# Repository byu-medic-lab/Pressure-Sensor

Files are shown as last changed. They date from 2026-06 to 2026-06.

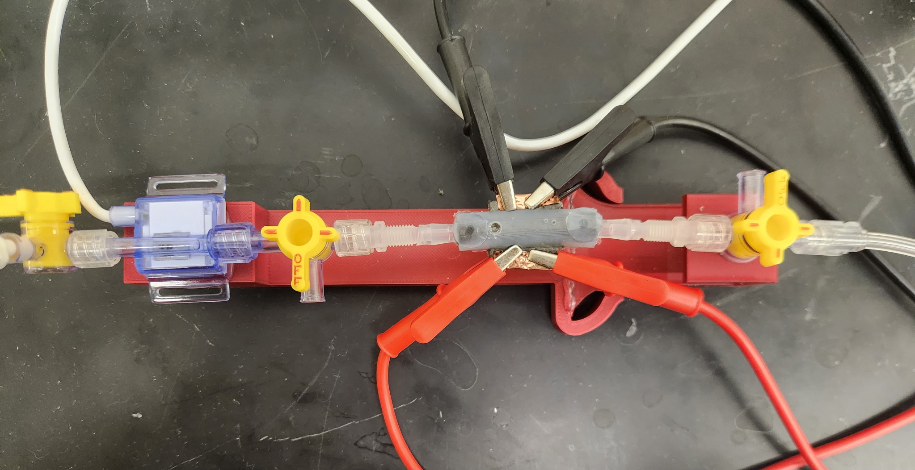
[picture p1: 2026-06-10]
images/Sensor_Setup.jpg

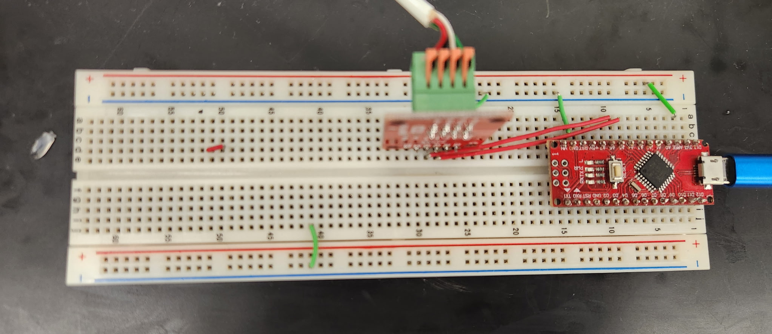
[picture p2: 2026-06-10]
images/Pressure_Sensor.jpg

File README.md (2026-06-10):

# Pressure Sensor Characterization System

This repository contains the software, setup notes, images, and 3D-print files for a lab pressure/resistance characterization system. The system is used to measure how the electrical resistance of a conductive polymer composite sensor changes under controlled pressure.

The main software is a Python desktop GUI built with PyQt6. It controls and records data from:

- A serial pressure sensor that outputs raw integer pressure readings
- A Fluke 8808A digital multimeter measuring resistance
- A New Era NE-500/NE-501 syringe pump over RS-232

The GUI supports pressure calibration, syringe pump movement calibration, automated pressure cycling, CSV logging, and SVG graph generation.

---

## Repository Layout

```text
Pressure-Sensor/
  README.md
  src/
    main.py
    pyproject.toml
    app/
    devices/
    gui/
    protocols/
    tests/
    hysteresis_tool/
    fluke_resistance_logger.py
    fluke_resistance_decay_graph.py
    pump_push_water_10s.py
    add_average_trendline_equations.py
  Instructions/
    Pressure_Resistance_Characterization_Setup.md
    Sensor_Fabrication_Protocol.md
    Sensor_Behavior.md
    Introduction.md
  images/
    Final_Sensor.png
    Fluke_Multimeter.jpg
    Manometer.jpg
    Pressure_Sensor.jpg
    Sensor_Setup.jpg
    Syringe_Pump.jpg
  STL/
    NCCF_Bottom.STL
    NCCF_Top.STL
    Silicone_Bottom.STL
    Silicone_Top.STL
```

The runnable Python project is inside the `src/` folder.

---

## Hardware Used

The software is designed for this lab setup:

- Pressure sensor connected through a serial interface
- Fluke 8808A digital multimeter
- NE-500/NE-501 syringe pump
- USB-to-serial adapters
- Water manometer
- Conductive polymer composite sensor fixture
- 3D printed sensor/test fixture components

The app can also run in simulation mode without hardware, but real data collection requires the devices above and the correct serial ports.

---

## Software Requirements

Install these before running the project:

- Python 3.11 or newer
- Git
- Windows is recommended because the GUI and serial-port workflow were developed and tested on Windows

Python packages are installed from `src/pyproject.toml`:

- PyQt6
- pyserial
- pytest, for running tests

---

## Download The Code From GitHub

Open PowerShell and run:

```powershell
cd "C:\Users\YOUR_USERNAME\Documents"
git clone https://github.com/byu-medic-lab/Pressure-Sensor.git
cd Pressure-Sensor
```

Replace `YOUR_USERNAME` with your Windows username if needed.

---

## Create The Python Environment

From the repository folder:

```powershell
cd src
python -m venv .venv
.venv\Scripts\activate
python -m pip install --upgrade pip
python -m pip install -e ".[test]"
```

This creates a local virtual environment and installs all required packages.

---

## Run The Tests

From the `src/` folder with the virtual environment activated:

```powershell
python -m pytest
```

All tests should pass before using the GUI for data collection.

---

## Run The Main GUI

From the `src/` folder with the virtual environment activated:

```powershell
python main.py
```

The GUI will open as a desktop application.

---

## Basic GUI Workflow

### 1. Prepare The System

Before starting:

- Select the correct serial port for each device
- Connect and test device communication
- Make sure the pressure system is vented to ambient
- Make sure the pressure sensor reading is stable
- Make sure the Fluke reading is stable
- Remove the water column unless doing manometer calibration
- Place the syringe pump at the known starting position
- Confirm the tubing and fluid path are ready before calibration or automated testing

### 2. Connect Devices

In the **Device connections** section:

- Select the pressure sensor serial port
- Select the Fluke serial port
- Select the syringe pump serial port
- Click **Connect** for each device
- Use **Test** to verify communication

Serial ports are not hardcoded. They must be selected from the dropdowns.

### 3. Calibrate Pressure With The Manometer

In the **Calibration** tab:

1. Enter the manometer pressure point in `cm H2O`
2. Set the recording time
3. Click **Start recording window**
4. The app records pressure samples for the selected time
5. The app averages the window and stores the point
6. The manometer point automatically increases by 10 cm H2O
7. Repeat for all calibration points
8. Click **Fit/save coefficients**

The pressure conversion used by the app is:

```text
mmHg = cmH2O * 0.735559
```

The fitted pressure model is:

```text
pressure_mmhg = slope * raw_pressure_integer + intercept
```

### 4. Calibrate Syringe Pump Movement

In the same **Calibration** tab:

1. Click **Start auto syringe calibration**
2. The app records pressure before movement
3. The pump moves using the fixed calibration sequence
4. The app records pressure after movement
5. The process repeats automatically
6. Click **Fit syringe calibration** when complete

The current fixed syringe calibration sequence uses:

```text
Pump motion time: 5 s
Movement rate: 60 mL/min
Direction: INF first
Average time: 5 s
Cycles: 5 up and 5 back
```

The app fits separate increasing and decreasing pump-response behavior.

### 5. Run Automated Test

In **Run automated test**:

1. Enter an experiment ID
2. Add operator notes
3. Choose an output folder
4. Enter start pressure, stop pressure, pressure interval, and optional cycle count
5. Leave time interval blank to use the automatic 3-tau settling behavior
6. Click **Start automated test**

The app moves to the start pressure before logging begins. During the test it records pressure and resistance at stopped pressure intervals.

---

## Output Files

Each automated run creates a timestamped output folder. The final folder normally contains:

```text
metadata.csv
resistance_vs_pressure_mmhg.svg
resistance_vs_pressure_fits.svg
plotted_pressure_resistance_points.csv
pressure_cm_vs_mmhg_points.csv
```

`metadata.csv` contains run information such as experiment ID, operator notes, serial settings, and calibration coefficients.

`plotted_pressure_resistance_points.csv` contains only:

```text
average_pressure_mmhg
average_resistance_ohms
```

The SVG graphs include equation text for average increasing and decreasing pressure sweeps.

---

## Standalone Scripts

The `src/` folder includes several standalone helper scripts.

### Fluke Resistance Logger

Records Fluke resistance vs time without opening the main GUI:

```powershell
python fluke_resistance_logger.py
```

This creates CSV and SVG files in:

```text
src/fluke_logs/
```

Only one program can use the Fluke COM port at a time. Close or disconnect the main GUI before running this logger.

### Fluke Exponential Decay Graph

Creates a resistance-vs-time graph with an exponential fit and 3-tau marker:

```powershell
python fluke_resistance_decay_graph.py
```

By default it uses the newest CSV in `fluke_logs/`.

### Pump Test Script

Runs the syringe pump for a short timed movement:

```powershell
python pump_push_water_10s.py
```

Only run this when the pump is physically safe to move.

### Add Average Trendline Equations To Existing Graphs

Walks a folder of saved runs and adds increasing/decreasing equation text to existing resistance-vs-pressure SVGs:

```powershell
python add_average_trendline_equations.py
```

### Hysteresis Tools

Additional post-processing tools are in:

```text
src/hysteresis_tool/
```

See:

```text
src/hysteresis_tool/README.md
```

---

## Important Notes

- Do not open PuTTY separately while the GUI is reading the pressure sensor. Only one program should own a serial port at a time.
- Do not run the standalone Fluke logger while the main GUI is connected to the Fluke.
- Do not run pump scripts unless the fluid path is safe and the pump is correctly connected.
- The app timestamps device data as it arrives and correlates pressure/resistance later by timestamp.
- Raw and averaged data are logged to CSV files.
- The GUI is designed so serial I/O runs in worker threads and does not block the interface.

---

## Troubleshooting

### PyQt6 Import Error

If Python cannot import PyQt6, reinstall the project dependencies:

```powershell
cd src
.venv\Scripts\activate
python -m pip install -e ".[test]"
```

### Serial Port Access Denied

This usually means another program is already using the port. Close:

- PuTTY
- The main GUI
- Any standalone logger script
- Any other serial monitor

Then unplug and reconnect the USB-to-serial adapter if needed.

### Fluke Reads Prompt-Only Responses

The software uses `VAL1?` for the Fluke primary display reading. If responses look wrong:

- Confirm the correct COM port
- Confirm the Fluke is set up for remote serial communication
- Confirm the baud rate is 9600
- Confirm the Fluke is in the desired resistance mode

### Pump Does Not Move

Check:

- Correct pump COM port
- Pump power and RS-232 cable
- Baud rate 19200
- Pump address/settings
- Physical syringe setup
- Tubing is not blocked

---

## Development Notes

The code is organized by responsibility:

- `app/` contains controller, calibration, logging, state machine, and analysis logic
- `devices/` contains threaded device workers
- `protocols/` contains serial command/response formatting
- `gui/` contains PyQt6 window and widgets
- `tests/` contains protocol, calibration, logging, and state-machine tests

Run tests after code changes:

```powershell
cd src
.venv\Scripts\activate
python -m pytest
```

---

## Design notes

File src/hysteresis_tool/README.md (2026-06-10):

# Hysteresis Graph Tool

Standalone tool for creating a resistance-vs-pressure hysteresis graph from:

```text
plotted_pressure_resistance_points.csv
```

It does not import or control the calibration GUI, does not open serial ports, and only reads the CSV file you give it.

## Run

From this folder:

```powershell
python hysteresis_graph.py "C:\path\to\run_folder\plotted_pressure_resistance_points.csv"
```

Or pass the run folder itself:

```powershell
python hysteresis_graph.py "C:\path\to\run_folder"
```

By default it writes:

```text
hysteresis_resistance_pressure.svg
hysteresis_resistance_pressure_without_first_cycle.svg
hysteresis_resistance_pressure_normalized.svg
figure_b_normalized_resistance_vs_pressure.svg
figure_c_hysteresis_area_vs_cycle.svg
```

next to the input CSV.

## Optional Output Path

```powershell
python hysteresis_graph.py "C:\path\to\plotted_pressure_resistance_points.csv" --output "C:\path\to\hysteresis.svg"
```

## Watch Mode

To keep regenerating the graph while a CSV is updated:

```powershell
python hysteresis_graph.py "C:\path\to\run_folder" --watch 10
```

That refreshes every 10 seconds. The tool still only reads the input file and writes its own SVG.

## Pressure And Resistance Over Points

To create a dual-axis graph with pressure and resistance as separate lines:

```powershell
python pressure_resistance_time_graph.py "C:\path\to\run_folder"
```

It writes:

```text
pressure_resistance_over_points.svg
```

## Staircase Range Graphs

To compare the first and second staircase blocks for 0-50, 0-100, and 0-150:

```powershell
python staircase_range_graphs.py "C:\path\to\run_folder"
```

It writes:

```text
staircase_0_50_comparison.svg
staircase_0_100_comparison.svg
staircase_0_150_comparison.svg
staircase_0_50_comparison_normalized.svg
staircase_0_100_comparison_normalized.svg
staircase_0_150_comparison_normalized.svg
```

In each graph, the first three cycles for that range are red, the later three cycles are blue, increasing pressure is solid, and decreasing pressure is dashed.

## Resistance Vs Pressure Without Cycles 9 And 10

To recreate the resistance-vs-pressure graph while removing cycles 9 and 10:

```powershell
python resistance_pressure_exclude_cycles.py "C:\path\to\run_folder"
```

It writes:

```text
resistance_vs_pressure_mmhg_without_cycles_9_10.svg
```

You can remove different cycles by changing the comma-separated list:

```powershell
python resistance_pressure_exclude_cycles.py "C:\path\to\run_folder" --exclude 2,7
```

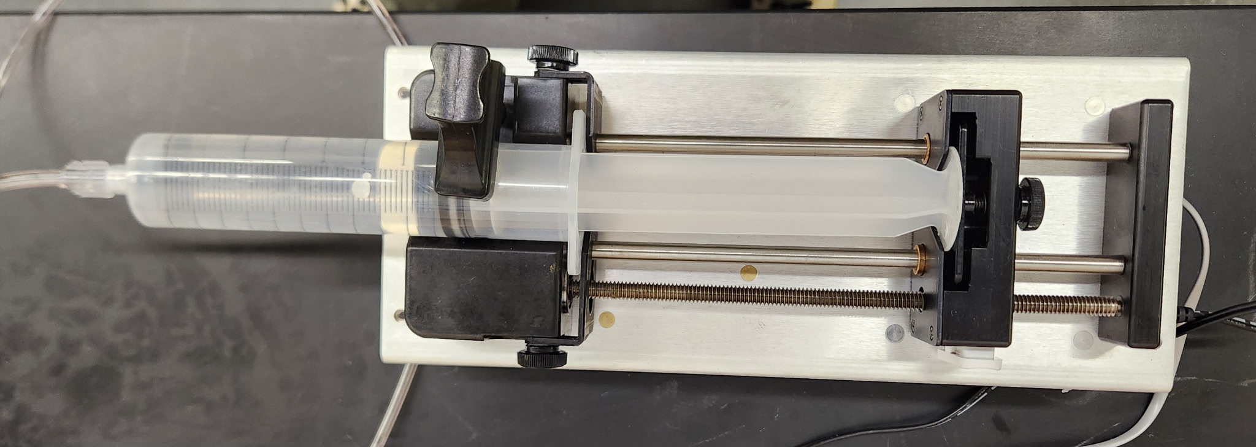
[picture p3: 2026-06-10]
images/Syringe_Pump.jpg

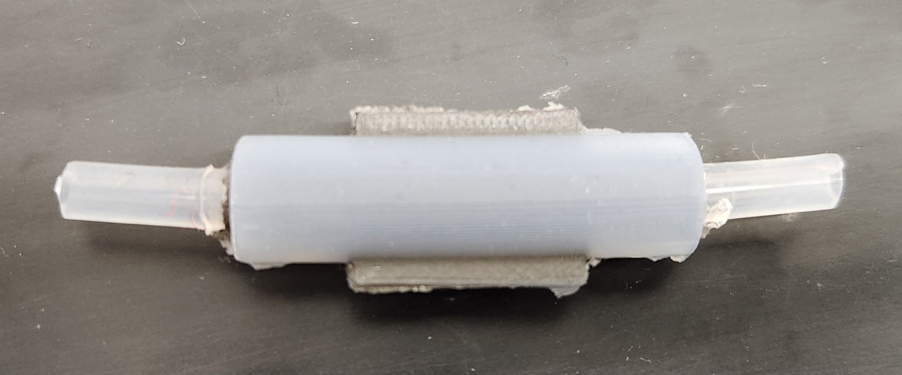
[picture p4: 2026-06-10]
images/Final_Sensor.png

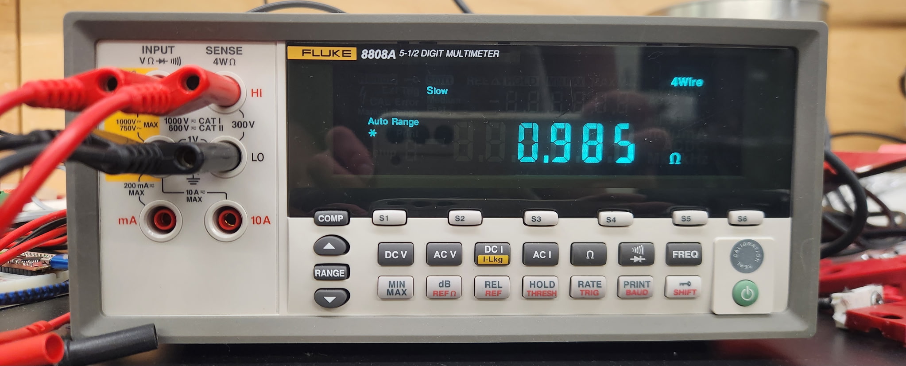
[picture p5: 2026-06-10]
images/Fluke_Multimeter.jpg

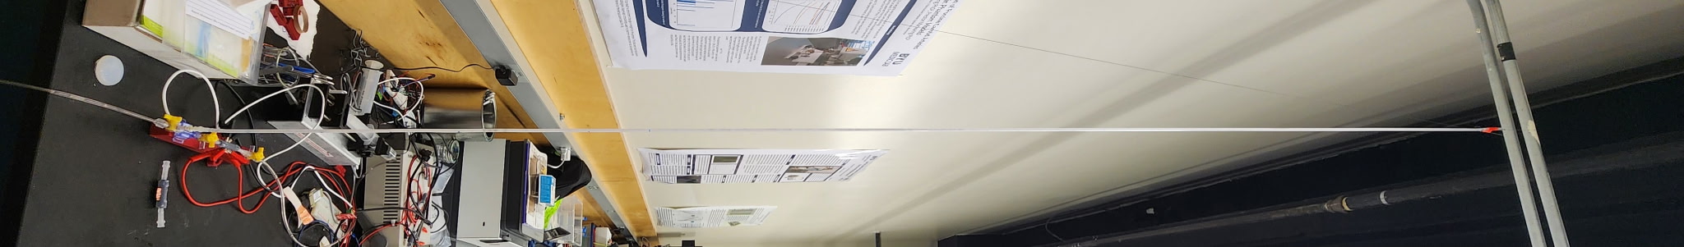
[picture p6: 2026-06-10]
images/Manometer.jpg

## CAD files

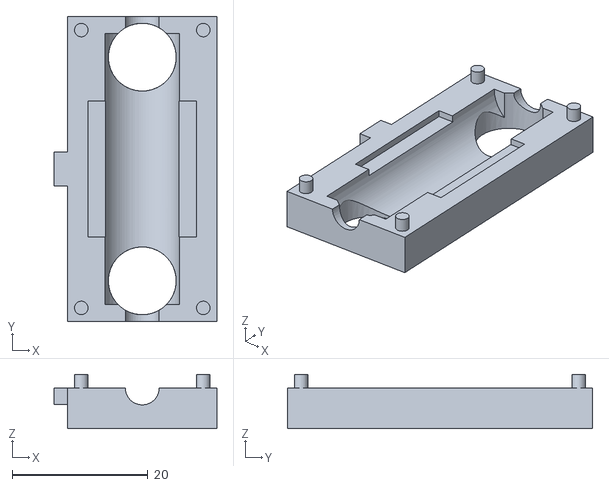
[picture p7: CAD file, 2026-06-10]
STL/Silicone_Top.STL
24.0 x 45.0 x 8.00

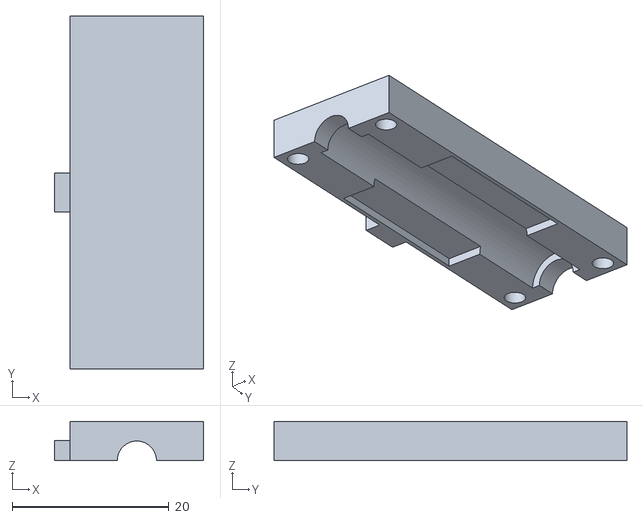
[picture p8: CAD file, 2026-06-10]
STL/NCCF_Bottom.STL
19.0 x 45.0 x 5.00

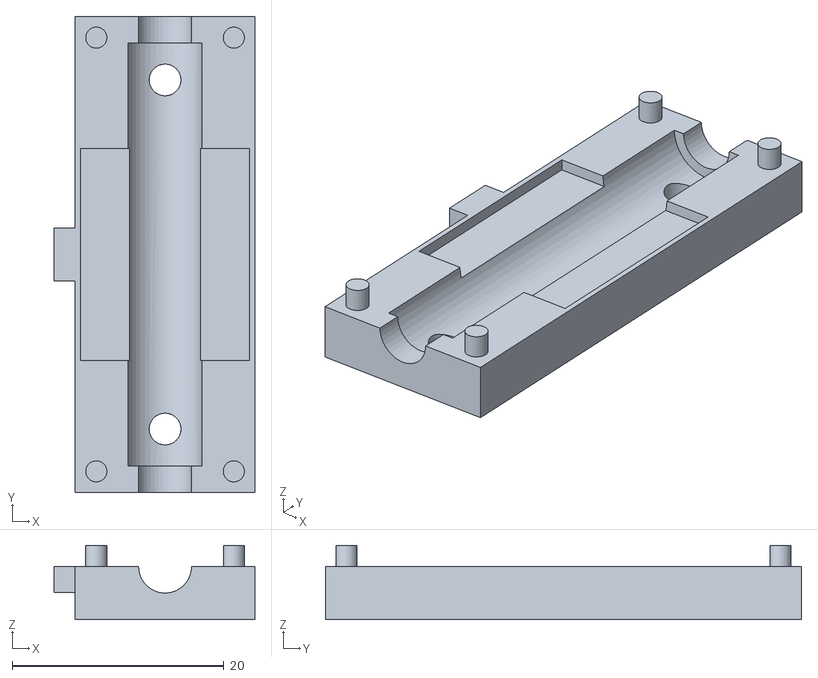
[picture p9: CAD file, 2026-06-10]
STL/NCCF_Top.STL
19.0 x 45.0 x 7.00

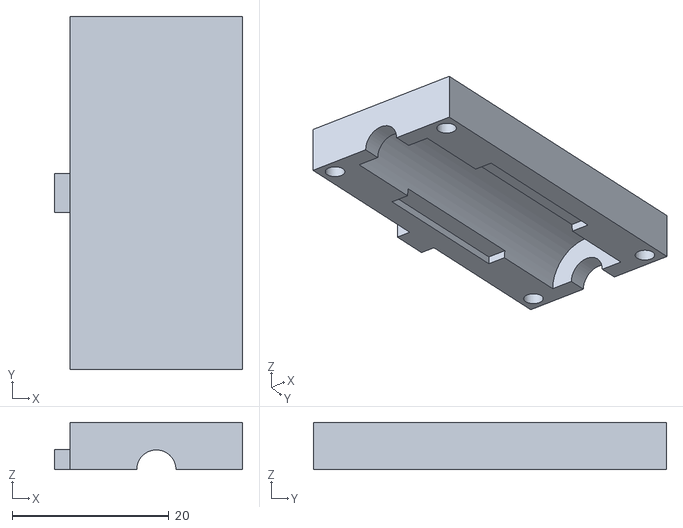
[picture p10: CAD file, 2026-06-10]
STL/Silicone_Bottom.STL
24.0 x 45.0 x 6.00

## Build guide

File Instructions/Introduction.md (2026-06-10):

# Introduction

## Project Overview

Conductive polymer composites (CPCs) are an emerging class of flexible sensing materials that can change their electrical resistance in response to mechanical deformation. Because CPCs can be fabricated into soft, stretchable structures, they have attracted significant interest for use in wearable electronics, soft robotics, biomedical devices, human motion monitoring, and flexible pressure sensing applications.

Traditional strain gauges are often rigid and are designed to operate over relatively small strain ranges. In contrast, CPC sensors can conform to curved surfaces and undergo much larger deformations while maintaining electrical functionality. These properties make CPCs attractive candidates for future flexible electronic systems.

The long-term goal of this project is to understand how CPC sensor resistance changes in response to mechanical deformation and to develop models that can predict strain using only electrical resistance measurements.

---

# Project Goals

The primary goals of this project are:

1. Measure pressure and sensor resistance simultaneously.
2. Characterize sensor behavior, including drift, hysteresis, and preconditioning effects.
3. Develop relationships between pressure and resistance.
4. Determine the relationship between strain and resistance.
5. Develop predictive models capable of estimating strain from measured resistance.

Ultimately, the objective is to determine whether CPC sensors can be used as reliable strain sensing elements in flexible electronic systems.

---

# Motivation

A significant amount of CPC research has focused on uniaxial strain testing, where a sensor is stretched along a single axis while its electrical response is measured. While these experiments are useful for understanding material behavior, many real-world applications do not experience purely uniaxial deformation.

In biomedical devices, soft robotic actuators, expandable tubing, and other flexible structures, deformation often occurs through radial expansion caused by internal pressure. This type of loading produces circumferential strain rather than simple uniaxial strain.

As a result, it is important to understand how CPC sensors behave when subjected to circumferential strain and whether the behaviors observed during uniaxial testing remain valid under more application-relevant loading conditions.

---

# Circumferential Strain Testing

Rather than stretching the sensor directly, this project generates circumferential strain by pressurizing flexible tubing.

As internal pressure increases, the tubing expands radially. This expansion stretches the CPC sensor and changes its electrical resistance.

The applied pressure is generated using a water manometer. Water is added to or removed from the manometer using a syringe pump, which changes the height of the water column.

The pressure applied to the sensor is determined from the water height and converted into millimeters of mercury (mmHg) using standard hydrostatic pressure relationships.

By controlling the water height, repeatable pressure profiles can be applied to the CPC sensor while its electrical response is measured.

---

# Data Acquisition System

A custom graphical user interface (GUI) was developed to automate data collection and experimental control.

The GUI performs three primary tasks:

1. Measures pressure using an inline pressure transducer.
2. Measures CPC sensor resistance using a Fluke 8808A Digital Multimeter.
3. Controls the syringe pump used to adjust the water level within the manometer.

By integrating these systems into a single interface, pressure and resistance data can be collected simultaneously and synchronized automatically.

---

# Pressure Cycling Experiments

The primary function of the GUI is to automate pressure cycling experiments.

During a test, the system cycles between a user-defined start pressure and end pressure using specified pressure increments. At each pressure level, data is collected for a defined period of time.

Rather than storing individual measurements directly for analysis, the GUI calculates average pressure and average resistance values over the collection period.

These averaged values are then used to generate pressure-resistance plots that characterize sensor behavior.

This averaging process helps reduce measurement noise and provides a more stable representation of the sensor response at each pressure level.

---

# Pressure, Resistance, and Strain Relationships

A major objective of this work is to determine how pressure, strain, and resistance are related.

The current testing platform directly measures:

- Pressure
- Resistance

However, strain is not currently measured.

The working assumption is that increasing pressure causes the tubing to expand, creating strain within the CPC sensor. This strain then alters the conductive pathways within the composite, producing a measurable resistance change.

Future work will focus on directly measuring strain using a camera-based imaging system. By tracking sensor deformation during pressurization, pressure, strain, and resistance data can be collected simultaneously.

This will allow the relationships between:

Pressure → Strain

and

Strain → Resistance

to be quantified independently.

---

# Long-Term Vision

The long-term goal of this project is to create a model capable of predicting sensor strain from electrical resistance measurements alone.

Such a model could allow CPC sensors to function as embedded sensing elements within flexible structures, eliminating the need for external strain measurement systems.

If successful, this approach could contribute to the development of future flexible electronic technologies, including wearable devices, biomedical monitoring systems, soft robotic actuators, and other applications requiring lightweight and compliant sensing solutions.

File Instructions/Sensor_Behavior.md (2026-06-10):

# Sensor Behavior

## Overview

This document summarizes the behavior observed in conductive polymer composite (CPC) sensors tested using the pressure characterization setup. The observations described here are based on experimental data collected to date and should be considered preliminary. As additional testing is performed, the explanations and hypotheses presented in this document may be revised.

---

# Key Observations

Several consistent behaviors have been observed across multiple sensors and testing protocols:

1. Electrical drift
2. Hysteresis
3. Cycle-to-cycle resistance changes
4. Preconditioning effects
5. Non-monotonic behavior under certain conditions

These phenomena have been reported in the CPC literature and are common challenges when using conductive polymer composites as strain sensors.

---

# Electrical Drift

The most consistent observation throughout testing has been electrical drift.

When sensors are subjected to repeated pressure cycles, the baseline resistance often changes over time. In many experiments, the resistance measured at the end of a pressure cycle is greater than the resistance measured at the beginning of the cycle, even when the pressure has returned to the same value.

This behavior causes the resistance-pressure relationship to shift over time and complicates direct pressure estimation using resistance alone.

Several potential mechanisms have been proposed in the literature, including:

- Viscoelastic relaxation of the polymer matrix
- Rearrangement of conductive pathways
- Progressive depercolation of the conductive network
- Time-dependent tunneling distance changes between conductive fillers

At present, the exact cause of the observed drift in these sensors remains unknown.

---

# Hysteresis

All sensors tested to date exhibit hysteresis.

For a given pressure, the measured resistance depends on whether the pressure is increasing or decreasing. As a result, loading and unloading curves do not overlap.

The hysteresis magnitude varies between sensors and testing protocols but is consistently present.

This behavior is expected in conductive polymer composites due to:

- Polymer viscoelasticity
- Delayed mechanical recovery
- Time-dependent restructuring of conductive pathways

The presence of hysteresis limits the ability to uniquely determine pressure from resistance without additional compensation methods.

---

# Cycle-to-Cycle Resistance Changes

Repeated pressure cycling frequently produces a gradual increase in resistance between cycles.

In many experiments:

- The first cycle produces the largest response.
- Subsequent cycles produce different resistance-pressure relationships.
- Baseline resistance often increases with continued cycling.

This behavior suggests that the conductive network is changing during repeated loading.

The effect is particularly noticeable during large pressure excursions and long-duration experiments.

---

# Preconditioning Effects

Several experiments have shown evidence of sensor preconditioning.

Preconditioning refers to changes in sensor behavior caused by previous loading history.

Examples observed during testing include:

- Reduced drift after repeated cycling within a specific pressure range.
- Improved repeatability after several initial cycles.
- Different responses after overnight rest periods.
- Changes in behavior following exposure to higher pressures.

In some cases, sensors that initially showed strong resistance increases with pressure later exhibited reduced sensitivity or even reversed trends after repeated loading.

These observations suggest that the conductive network evolves as the sensor experiences mechanical strain.

Identifying stable operating regions through preconditioning may be necessary before reliable measurements can be obtained.

---

# Depercolation Strain

One of the major unanswered questions is the strain level at which depercolation occurs.

Depercolation refers to the breakdown of conductive pathways within the composite as strain increases.

Many CPC sensors exhibit a transition between:

- A relatively stable conductive state
- A highly strain-sensitive depercolation region

At present, the strain experienced by the sensor is not directly measured during testing.

Because strain data is unavailable, it is currently impossible to determine:

- The strain at which depercolation begins
- Whether the sensor is operating below, near, or above the depercolation threshold
- How pressure relates to actual sensor strain

Future work should include direct strain measurements.

A recommended approach is to implement a camera-based measurement system capable of tracking changes in sensor geometry during pressurization. Image-based strain measurements would allow pressure, strain, and resistance data to be analyzed simultaneously.

---

# Comparison to Published Literature

All research papers reviewed to date are stored in Zotero under the folder:

- Strain Gauge and Electrodes

Researchers have reported several behaviors that closely resemble the observations made in this project.

Commonly reported CPC phenomena include:

- Electrical drift
- Hysteresis
- Viscoelastic relaxation
- Resistance baseline shifts
- Preconditioning effects
- Nonlinear sensitivity
- Depercolation-driven behavior

Many publications describe conductive networks that continue to evolve during repeated loading cycles. This often produces changing resistance responses even when identical mechanical loading conditions are applied.

Several studies also report that the first few loading cycles differ substantially from later cycles, suggesting that conductive pathways rearrange as the material is mechanically conditioned.

These observations are generally consistent with the behavior observed in the sensors tested in this project.

---

# Notable Differences from Literature

Although many of the observed behaviors match published results, several questions remain unresolved.

In particular:

- The exact strain experienced by the sensor is unknown.
- The location of the depercolation threshold has not been identified.
- The source of long-term drift remains unclear.
- The relationship between pressure, strain, and resistance has not yet been fully characterized.

Additional experiments combining pressure measurements, resistance measurements, and direct strain measurements will be required to determine whether the observed behavior is consistent with published depercolation models.

---

# Future Work

Recommended future investigations include:

1. Implement camera-based strain measurements.
2. Determine the strain corresponding to various pressure levels.
3. Identify the onset of depercolation.
4. Quantify preconditioning effects.
5. Investigate the effects of overnight rest periods.
6. Compare sensors fabricated with different filler concentrations.
7. Develop models capable of compensating for drift and hysteresis.
8. Evaluate whether stable operating regions exist for long-term sensing applications.

As additional data is collected, this document should be updated to reflect new observations and conclusions.

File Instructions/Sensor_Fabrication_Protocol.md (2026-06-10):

# Flexible Conductive Silicone Pressure Sensor Fabrication Protocol

## Purpose

This document describes the fabrication process used to create a flexible conductive silicone pressure sensor consisting of a conductive polymer composite sheath surrounding silicone tubing and encapsulated within an outer silicone layer.

---

# Sensor Structure

### Layer Description

1. **Silicone Tubing Core** – Fluid path used for pressure transmission.
2. **Conductive Composite Sheath** – Fabricated from silicone, NCCF, BNS, and silicone oil. Changes resistance as the tubing expands.
3. **Outer Silicone Encapsulation** – Protects the conductive layer and improves durability.

### Fabrication Order

1. Insert stainless steel rod into tubing.
2. Mold conductive composite sheath around tubing.
3. Cure conductive composite.
4. Mold outer silicone encapsulation.
5. Final cure and trim excess material.

---

# Materials

## Sensor Materials

- Silicone Rubber Part A (Let's Resin, Hardness 0A)
- Silicone Rubber Part B (Let's Resin, Hardness 0A)
- Precision Coated and Converted Fibers (PC2F / NCCF), Product #1AC1PC-0.5
- Branched Nickel Strands (BNS), Product #3AA150
- Silicone Oil (MicroLubrol Type 200 Fluid Silicone Oil, 50 cSt)

## Fabrication Materials

- Silicone tubing (approximately 3 mm inner diameter and 5 mm outer diameter)
- Trigger clamps
- Stainless steel rod or needle stock sized to fit through the tubing lumen
- Scale
- Vacuum chamber
- Beakers
- Glass stirring rod
- Disposable weighing boats
- Pipettes (tips cut to act as small scoops)
- Scissors
- 3D printed molds

---

# Composite Formulations

## Recipe 1

| Material | Mass (g) |
|---|---:|
| Silicone Part A | 4.000 |
| Silicone Part B | 4.000 |
| NCCF | 0.528 |
| BNS | 2.202 |
| Silicone Oil | 0.506 |

Total Batch Mass: 11.236 g

## Recipe 2

| Material | Mass (g) |
|---|---:|
| Silicone Part A | 4.000 |
| Silicone Part B | 4.000 |
| NCCF | 1.330 |
| BNS | 0.413 |
| Silicone Oil | 0.333 |

Total Batch Mass: 10.076 g

Fifty percent of Silicone Part A and Silicone Part B are reserved for fabrication of the outer silicone encapsulation layer.

---

# 3D Printed Components

## Printer Settings

- Printer: Original Prusa XL – 5T Input Shaper
- Nozzle: 0.4 mm
- Filament: Prusa PLA

## Repository Structure

```text
Pressure-Sensor/STL/
├── NCCF_Top.STL
├── NCCF_Bottom.STL
├── Silicone_Top.STL
└── Silicone_Bottom.STL

Pressure-Sensor/images/
└── Final_Sensor.png
```

---

# Fabrication Procedure

## 1. Prepare Materials

1. Measure all materials by weight according to the selected formulation.
2. Place materials into disposable weighing boats.
3. Cut the ends off pipettes to create small scoops for handling fibers and powders.

## 2. Prepare Conductive Composite

1. Add silicone oil to the BNS.
2. Mix thoroughly using a glass stirring rod.
3. Divide the BNS/oil mixture equally between two beakers.
4. Divide the NCCF equally into two portions.
5. Add one NCCF portion to Silicone Part A.
6. Add the second NCCF portion to Silicone Part B.
7. Mix each silicone/NCCF mixture thoroughly.
8. Add one silicone mixture to one BNS/oil beaker.
9. Add the second silicone mixture to the remaining BNS/oil beaker.
10. Mix both beakers until homogeneous.
11. Combine both beakers into a single beaker.
12. Stir continuously for 15 minutes.

## 3. Degas Composite

1. Place the composite mixture into a vacuum chamber.
2. Apply vacuum until trapped air bubbles are removed.
3. The chamber gauge typically indicated approximately 25 Pa.
4. Continue degassing for 30 minutes.

> The exact pressure is not critical. The objective is complete removal of visible bubbles.

## 4. Prepare Tubing

1. Cut a 2.5 inch (63.5 mm) section of silicone tubing.
2. Insert a stainless steel rod through the tubing lumen.
3. Ensure the tubing remains straight during molding.

## 5. Mold Conductive Composite Layer

1. Fill the conductive composite bottom mold with the degassed composite.
2. Place the tubing into the mold slots.
3. Fill the conductive composite top mold with composite material.
4. Assemble the mold halves.
5. Secure the mold using trigger clamps.
6. Verify that the tubing remains centered.

### Cure Conditions

- Room temperature cure
- Minimum cure time: 4 hours

## 6. Prepare Outer Silicone Layer

1. Mix equal parts Silicone Part A and Silicone Part B.
2. Stir for approximately 1 minute.
3. Degas in the vacuum chamber for 30 minutes.

During degassing:

1. Remove the cured conductive composite sheath from its mold.
2. Trim excess material using scissors.

## 7. Mold Outer Silicone Encapsulation

1. Fill the silicone bottom mold with the degassed silicone.
2. Place the conductive composite sheath into the mold.
3. Fill the silicone top mold with silicone.
4. Assemble the mold.
5. Secure the mold using trigger clamps.
6. Add additional silicone through the fill holes until completely full.

### Cure Conditions

- Room temperature cure
- Minimum cure time: 6 hours

## 8. Demolding

1. Remove the sensor from the mold.
2. Trim excess silicone.
3. Inspect according to the acceptance criteria below.

---

# Acceptance Criteria

A successfully fabricated sensor should meet the following requirements:

- No visible air bubbles or large voids
- Tubing lumen remains open and unobstructed
- Conductive sheath is continuous around the tubing
- Outer silicone layer fully encapsulates the conductive composite
- Sensor can be removed from the mold without tearing

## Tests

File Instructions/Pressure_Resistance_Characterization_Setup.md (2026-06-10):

# Pressure and Resistance Characterization Test Setup

## Overview

This setup is used to characterize the electrical resistance response of a conductive polymer composite (CPC) sensor under controlled hydrostatic pressure conditions. Pressure is determined by the height of a water column within a manometer and is monitored using an inline pressure transducer connected to an Arduino Nano and SparkFun Qwiic Scale board. Sensor resistance is measured simultaneously using a Fluke 8808A Digital Multimeter configured for four-wire resistance measurements.

The water level within the manometer is adjusted using a syringe pump, allowing automated and repeatable pressure profiles. Pressure and resistance measurements are collected and synchronized through a custom graphical user interface (GUI).

The setup consists of the following subsystems:

1. Structural Base Assembly
2. CPC Sensor Assembly
3. Water Manometer
4. Pressure Measurement System
5. Syringe Pump Control System
6. Data Acquisition System

---

# Materials

## Fluidic Components

- Medical-grade tubing (approximately 8.5 ft used for the manometer)
- Medical-grade tubing with male-to-female luer fittings
- 2 × Female Luer Lock to Barb adapters
- 1 × Male-to-Male Luer adapter
- 2 × Three-way stopcocks
- Inline pressure sensor (flow-through pressure transducer)
- Water

## Sensor Components

- Conductive Polymer Composite (CPC) sensor
- Copper tape
- 4 × Alligator clip test leads

## Electronics

- Arduino Nano (ATmega328P)
- Breadboard
- SparkFun Qwiic Scale (NAU7802)
- Qwiic cable (JST-SH 4-pin)
- Micro-USB cable

## Instrumentation

- Fluke 8808A Digital Multimeter
- New Era Pump Systems NE-510L Syringe Pump
- Syringe (diameter not critical)

## Computer Interface Components

- Sabrent HB-UM43 USB Hub
- RJ45 modular communication cable
- DB9 female-to-female null modem adapter
- USB-to-Serial adapter (DB9 female)

## Mechanical Components

- Custom 3D printed base
- Strong adhesive
- Hot glue

---

# System Overview

The system consists of a water-filled manometer connected to a CPC sensor and an inline pressure transducer. Water is added to or removed from the manometer using a syringe pump, changing the height of the water column and therefore the pressure applied to the sensor.

The pressure transducer continuously measures system pressure and transmits the data to an Arduino Nano through a SparkFun Qwiic Scale board. Simultaneously, the Fluke 8808A records the resistance of the CPC sensor using a four-wire measurement configuration.

Pressure and resistance data are collected and synchronized through the data acquisition software.

---

# Mechanical Assembly

## 3D Printed Base

No STL files are currently available for the base.

A suitable replacement can be fabricated using the following approximate dimensions:

- Base length: 20 cm
- Base width: 3 cm
- Platform height: 3 cm
- First platform inward extension: 3 cm
- Second platform inward extension: 4.5 cm

Secure the base to a rigid work surface using strong adhesive to prevent movement during testing.

The base supports:

- One inline pressure transducer
- Two three-way stopcocks

Mount the pressure transducer to one end of the base using hot glue.

Mount both stopcocks using hot glue such that:

- The valve handles remain accessible
- The fluid path is visible
- The CPC sensor can be installed between them

Reference: Pressure-Sensor/images/Sensor_Setup.jpg

---

# CPC Sensor Fabrication

The CPC sensor used in this setup is fabricated separately from the testing apparatus.

Fabrication instructions, material recipes, mold construction procedures, curing procedures, and electrical connection methods are provided in a separate document within this repository.

Before beginning testing:

1. Verify that the sensor tubing is free of leaks.
2. Verify that both conductive flaps are electrically continuous.
3. Verify that the luer fittings are securely attached.
4. Inspect the sensor for visible defects or damage.

Reference: Pressure-Sensor/images/Sensor_Setup.jpg

---

# CPC Sensor Assembly

## Preparing the Sensor

1. Insert a Female Luer Lock to Barb adapter into each end of the CPC sensor tubing.
2. Ensure the tubing is fully seated on both barb fittings.
3. Apply folded pieces of copper tape to the conductive flaps extending from the sensor.

## Four-Wire Resistance Connections

Attach four alligator clips to the copper tape.

### Positive Side

- Current Positive (I+)
- Voltage Positive (V+)

### Negative Side

- Current Negative (I−)
- Voltage Negative (V−)

This creates a four-wire Kelvin resistance measurement configuration.

## Installing the Sensor

Install the CPC sensor between the two stopcocks mounted on the base.

Connect:

- One female luer fitting to the upstream stopcock
- One female luer fitting to the downstream stopcock

Reference: Pressure-Sensor/images/Sensor_Setup.jpg

---

# Water Manometer Assembly

## Purpose

The manometer provides a known hydrostatic pressure reference for sensor characterization and pressure sensor calibration.

## Construction

1. Suspend approximately 8.5 ft of medical-grade tubing vertically.
2. Secure the tubing to a ceiling, wall, or other rigid structure.
3. Ensure the tubing hangs as vertically as possible.
4. Fill the tubing with water.

The tubing diameter is not critical because pressure is determined by water column height rather than tubing diameter.

## Connections

1. Attach a Male-to-Male Luer adapter to the end of the manometer tubing.
2. Connect the adapter to a three-way stopcock.
3. Connect the stopcock to the pressure transducer assembly.

Reference: Pressure-Sensor/images/Manometer.jpg

---

# Pressure Calculation

The pressure applied to the sensor is determined by the height of the water column.

Pressure can be calculated using:

Pressure (mmHg) = Height (cm H₂O) × 0.7356

where:

- Height is measured in centimeters of water (cm H₂O)
- Pressure is reported in millimeters of mercury (mmHg)

## Example Values

| Water Height (cm H₂O) | Pressure (mmHg) |
|---|---|
| 10 | 7.36 |
| 20 | 14.71 |
| 30 | 22.07 |
| 40 | 29.42 |
| 50 | 36.78 |

The pressure transducer is calibrated against these known pressure values to determine the conversion between raw sensor readings and mmHg.

---

# Pressure Measurement System

## Hardware

- Arduino Nano (ATmega328P)
- SparkFun Qwiic Scale (NAU7802)
- Inline pressure transducer
- Breadboard
- Qwiic cable
- Micro-USB cable

## Breadboard Assembly

Mount the Arduino Nano and SparkFun Qwiic Scale on a solderless breadboard.

Connect the pressure transducer wiring to the SparkFun Qwiic Scale according to the board labeling.

The Arduino Nano communicates with the SparkFun Qwiic Scale and transmits pressure measurements to the data acquisition software.

Reference: Pressure-Sensor/images/Pressure_Sensor.jpg

---

# Syringe Pump Assembly

## Hardware

- New Era Pump Systems NE-510L Syringe Pump
- Syringe
- Medical-grade tubing

## Fluid Connections

1. Install the syringe into the syringe pump and secure it using the pump clamp.
2. Connect tubing to the syringe luer fitting.
3. Connect the opposite end of the tubing to the stopcock mounted on the base.
4. Verify that all fluidic connections are secure and that the system forms a continuous path between the syringe, manometer, pressure transducer, and CPC sensor.

Reference: Pressure-Sensor/images/Syringe_Pump.jpg

---

# Digital Multimeter Setup

## Hardware

- Fluke 8808A Digital Multimeter
- Four alligator clip leads

## Configuration

1. Connect all four alligator clips to the CPC sensor.
2. Connect the Fluke 8808A to the computer.
3. Select resistance measurement mode.
4. Press the resistance button twice to enable four-wire resistance measurements.

This configuration allows accurate resistance measurements while minimizing lead resistance effects.

Reference: Pressure-Sensor/images/Fluke_Multimeter.jpg

---

# Computer Connections

### Connection Summary

| Device | Connection Path |
|---|---|
| Arduino Nano | Micro-USB → USB Hub → Computer |
| Pressure Transducer | SparkFun Qwiic Scale → Arduino Nano |
| Syringe Pump | RJ45 Cable → Null Modem Adapter → USB-to-Serial Adapter → USB Hub → Computer |
| Fluke 8808A | USB-to-Serial Adapter → USB Hub → Computer |

---

# Data Collection Procedure

## GUI Setup

1. Connect the Arduino Nano, Fluke 8808A, and syringe pump to the computer through the USB hub.
2. Launch the data acquisition GUI.
3. Select the Arduino COM port.
4. Select the Fluke COM port.
5. Select the syringe pump COM port.
6. Verify communication with all connected devices.

## Pressure Sensor Calibration

1. Fill the fluidic system with water and remove visible air bubbles.
2. Set the manometer to a known water height.
3. Record the corresponding raw pressure sensor reading.
4. Repeat for multiple water heights.
5. Use the collected data to determine the pressure sensor conversion equation.

## Experimental Data Collection

1. Adjust the water level to the desired pressure.
2. Allow the system to stabilize.
3. Begin data collection.
4. Record pressure data from the pressure transducer.
5. Record resistance data from the Fluke 8808A.
6. Continue data collection for the desired duration.
7. Save all generated data files for later analysis.

The GUI synchronizes pressure measurements and resistance measurements for subsequent analysis.

---

# Notes

- The pressure transducer model is currently unknown.
- Ensure all luer connections are tightened before testing.
- Remove as many air bubbles as possible before collecting data.
- Verify stopcock positions before changing pressure.
- The tubing diameter used for the manometer is not critical because pressure is determined by water column height.
- Inspect CPC sensors for leaks or damaged conductive flaps before installation.

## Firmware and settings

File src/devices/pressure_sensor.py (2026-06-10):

"""Threaded pressure sensor worker with serial and simulation modes."""

from __future__ import annotations

import math
import random
import time
from queue import Empty, Queue
from typing import Any

from app.messages import CommandType, DeviceCommand, DeviceMessage, DeviceSource, MessageType, utc_now
from devices.base_device import BaseDeviceThread
from protocols.pressure_protocol import parse_pressure_integer


class PressureSensorThread(BaseDeviceThread):
    """PuTTY-style raw integer pressure sensor worker.

    The worker owns the serial port in hardware mode. Incoming serial lines are
    timestamped immediately after ``readline`` returns and before the sample is
    queued for the GUI/controller.
    """

    def __init__(self, sample_interval_s: float, outbound: Queue[DeviceMessage]) -> None:
        super().__init__(DeviceSource.PRESSURE, sample_interval_s, outbound)
        self._start = time.monotonic()
        self._ambient_raw = 10000
        self._serial: Any | None = None
        self._simulation_mode = True
        self._invalid_line_count = 0

    def run(self) -> None:
        while self.running:
            self._process_commands()
            if self.connected and self.acquiring:
                if self._simulation_mode:
                    now = time.monotonic()
                    if now - self._last_sample_monotonic >= self.sample_interval_s:
                        self._last_sample_monotonic = now
                        self.sample_once()
                else:
                    self._read_serial_once()
            time.sleep(0.002 if self.connected and self.acquiring and not self._simulation_mode else 0.01)
        self.close()

    def handle_command(self, command: DeviceCommand) -> None:
        try:
            if command.command_type == CommandType.CONNECT:
                self._connect(command)
            elif command.command_type == CommandType.DISCONNECT:
                self.close()
                self.emit_status("pressure disconnected.", command.request_id)
            elif command.command_type == CommandType.TEST_CONNECTION:
                self._test_connection(command)
            elif command.command_type == CommandType.ZERO:
                self._zero(command)
            else:
                super().handle_command(command)
        except Exception as exc:
            self.emit_error(str(exc), command.request_id)

    def _connect(self, command: DeviceCommand) -> None:
        self.close()
        self.port = str(command.payload.get("port", "SIM"))
        self.baud_rate = int(command.payload.get("baud_rate", 115200))
        self._simulation_mode = bool(command.payload.get("simulation", False)) or self.port.upper() == "SIM"
        if self._simulation_mode:
            self.connected = True
            self.emit_status("pressure connected in simulation mode.", command.request_id)
            return

        try:
            import serial
        except Exception as exc:
            raise RuntimeError("pyserial is required for pressure sensor hardware mode.") from exc

        self._serial = serial.Serial(
            port=self.port,
            baudrate=self.baud_rate,
            timeout=0.05,
            write_timeout=0.2,
        )
        self._serial.reset_input_buffer()
        self.connected = True
        self.emit_status(f"pressure connected on {self.port} at {self.baud_rate} baud.", command.request_id)

    def _test_connection(self, command: DeviceCommand) -> None:
        port = str(command.payload.get("port", "SIM"))
        simulation = bool(command.payload.get("simulation", False)) or port.upper() == "SIM"
        if simulation:
            self.emit_status("pressure simulation connection test passed.", command.request_id)
            return

        try:
            import serial
        except Exception as exc:
            raise RuntimeError("pyserial is required for pressure sensor connection tests.") from exc

        baud_rate = int(command.payload.get("baud_rate", 115200))
        last_error: Exception | None = None
        with serial.Serial(port=port, baudrate=baud_rate, timeout=0.5, write_timeout=0.2) as serial_port:
            for _ in range(20):
                line = serial_port.readline()
                timestamp = utc_now()
                if not line:
                    continue
                try:
                    raw_value = parse_pressure_integer(line)
                except ValueError as exc:
                    last_error = exc
                    continue
                break
            else:
                detail = f" Last invalid line: {last_error}" if last_error else ""
                raise RuntimeError(f"No valid pressure integer was read during connection test.{detail}")
        self.outbound.put(
            DeviceMessage(
                source=self.source,
                message_type=MessageType.DATA,
                timestamp=timestamp,
                payload=self._sample_payload(raw_value),
                request_id=command.request_id,
            )
        )
        self.emit_status(f"pressure connection test read raw value {raw_value}.", command.request_id)

    def _zero(self, command: DeviceCommand) -> None:
        if "raw_value" in command.payload:
            self._ambient_raw = int(command.payload["raw_value"])
            self.emit_status(f"pressure ambient zero set to {self._ambient_raw}.", command.request_id)
            return
        self.emit_warning("No raw value supplied for pressure zero; current ambient zero was unchanged.", command.request_id)

    def sample_once(self) -> None:
        timestamp = utc_now()
        elapsed = time.monotonic() - self._start
        signal = 2200 * (0.5 + 0.5 * math.sin(elapsed / 5.0))
        noise = random.randint(-18, 18)
        raw_value = max(0, int(self._ambient_raw + signal + noise))
        self.outbound.put(
            DeviceMessage(
                source=self.source,
                message_type=MessageType.DATA,
                timestamp=timestamp,
                payload=self._sample_payload(raw_value),
            )
        )

    def _read_serial_once(self) -> None:
        if self._serial is None:
            self.emit_error("Pressure serial port is not open.")
            self.acquiring = False
            return
        try:
            line = self._serial.readline()
        except Exception as exc:
            self.emit_error(f"Pressure serial read failed: {exc}")
            self.acquiring = False
            return
        if not line:
            return

        timestamp = utc_now()
        try:
            raw_value = parse_pressure_integer(line)
        except ValueError as exc:
            self._invalid_line_count += 1
            self.emit_warning(f"Ignored invalid pressure line #{self._invalid_line_count}: {exc}")
            return
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

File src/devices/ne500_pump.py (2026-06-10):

"""NE-500/NE-501 pump worker with serial and simulation modes."""

from __future__ import annotations

from queue import Queue
from typing import Any

from app.messages import CommandType, DeviceCommand, DeviceMessage, DeviceSource, MessageType, utc_now
from devices.base_device import BaseDeviceThread
from protocols import ne500_protocol


class NE500PumpThread(BaseDeviceThread):
    """Pump command worker with one-command-at-a-time serial semantics."""

    def __init__(self, sample_interval_s: float, outbound: Queue[DeviceMessage]) -> None:
        super().__init__(DeviceSource.PUMP, sample_interval_s, outbound)
        self.running_pump = False
        self.direction = "INF"
        self.rate = 1.0
        self.rate_units = "ML/MIN"
        self.volume_ml: float | None = 0.0
        self.mode = "incremental"
        self.diameter_mm: float | None = None
        self.distance_mm: float | None = None
        self.rate_mm_min: float | None = None
        self.motion_seconds: float | None = None
        self._serial: Any | None = None
        self._simulation_mode = True

    def handle_command(self, command: DeviceCommand) -> None:
        try:
            if command.command_type == CommandType.CONNECT:
                self._connect(command)
            elif command.command_type == CommandType.DISCONNECT:
                self.close()
                self.emit_status("pump disconnected.", command.request_id)
            elif command.command_type == CommandType.TEST_CONNECTION:
                self._test_connection(command)
            elif command.command_type in {CommandType.STOP, CommandType.ABORT}:
                self._stop_pump(command)
            else:
                super().handle_command(command)
        except Exception as exc:
            self.emit_error(str(exc), command.request_id)

    def _connect(self, command: DeviceCommand) -> None:
        self.close()
        self.port = str(command.payload.get("port", "SIM"))
        self.baud_rate = int(command.payload.get("baud_rate", 19200))
        self._simulation_mode = bool(command.payload.get("simulation", False)) or self.port.upper() == "SIM"
        if self._simulation_mode:
            self.connected = True
            self.emit_status("pump connected in simulation mode.", command.request_id)
            return

        try:
            import serial
        except Exception as exc:
            raise RuntimeError("pyserial is required for pump hardware mode.") from exc

        self._serial = serial.Serial(
            port=self.port,
            baudrate=self.baud_rate,
            bytesize=8,
            parity="N",
            stopbits=1,
            timeout=1.0,
            write_timeout=1.0,
        )
        self._serial.reset_input_buffer()
        self.connected = True
        self.emit_status(f"pump connected on {self.port} at {self.baud_rate} baud.", command.request_id)

    def _test_connection(self, command: DeviceCommand) -> None:
        port = str(command.payload.get("port", "SIM"))
        simulation = bool(command.payload.get("simulation", False)) or port.upper() == "SIM"
        if simulation:
            self.emit_status("pump simulation connection test passed.", command.request_id)
            return
        try:
            import serial
        except Exception as exc:
            raise RuntimeError("pyserial is required for pump connection tests.") from exc
        baud_rate = int(command.payload.get("baud_rate", 19200))
        with serial.Serial(port=port, baudrate=baud_rate, bytesize=8, parity="N", stopbits=1, timeout=1.0, write_timeout=1.0) as serial_port:
            serial_port.write(ne500_protocol.stop())
            serial_port.flush()
            response = serial_port.readline()
        self.emit_status(f"pump connection test sent STP; response: {ne500_protocol.decode_response(response) or '<none>'}", command.request_id)

    def handle_device_command(self, command: DeviceCommand) -> None:
        if command.command_type == CommandType.RUN:
            if not self.connected:
                raise RuntimeError("Pump is not connected.")
            self.direction = str(command.payload.get("direction", self.direction))
            self.rate = float(command.payload.get("rate", self.rate))
            self.rate_units = str(command.payload.get("rate_units", self.rate_units))
            self.volume_ml = float(command.payload.get("volume_ml", self.volume_ml or 0.0))
            self.mode = str(command.payload.get("mode", self.mode))
            self.diameter_mm = float(command.payload["diameter_mm"]) if command.payload.get("diameter_mm") else self.diameter_mm
            self.distance_mm = float(command.payload["distance_mm"]) if command.payload.get("distance_mm") else self.distance_mm
            self.rate_mm_min = float(command.payload["rate_mm_min"]) if command.payload.get("rate_mm_min") else self.rate_mm_min
            self.motion_seconds = float(command.payload["motion_seconds"]) if command.payload.get("motion_seconds") else self.motion_seconds
            if not self._simulation_mode:
                self._run_hardware_sequence()
            self.running_pump = True
            self.emit_status("Pump running.", command.request_id)
            self.sample_once()
        elif command.command_type in {CommandType.ABORT, CommandType.STOP}:
            self._stop_pump(command)
        else:
            super().handle_device_command(command)

    def sample_once(self) -> None:
        self.outbound.put(
            DeviceMessage(
                source=self.source,
                message_type=MessageType.DATA,
                timestamp=utc_now(),
                payload={
                    "running": self.running_pump,
                    "direction": self.direction,
                    "rate": self.rate,
                    "rate_units": self.rate_units,
                    "volume_ml": self.volume_ml,
                    "mode": self.mode,
                    "diameter_mm": self.diameter_mm,
                    "distance_mm": self.distance_mm,
                    "rate_mm_min": self.rate_mm_min,
                    "motion_seconds": self.motion_seconds,
                },
            )
        )

    def _run_hardware_sequence(self) -> None:
        if self._serial is None:
            raise RuntimeError("Pump serial port is not open.")
        if self.diameter_mm is not None and self.diameter_mm > 0:
            self._send_and_wait(ne500_protocol.diameter(self.diameter_mm))
        self._send_and_wait(ne500_protocol.rate(self.rate, self.rate_units))
        self._send_and_wait(ne500_protocol.direction(self.direction))
        requested_volume = 0.0 if self.mode == "continuous" else float(self.volume_ml or 0.0)
        self._send_and_wait(ne500_protocol.volume(requested_volume))
        self._send_and_wait(ne500_protocol.run())
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

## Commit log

2026-06-10 Rename NCCF Bottom.STL to NCCF_Bottom.STL
    [NCCF_Bottom.STL]
2026-06-10 Rename NCCF Top.STL to NCCF_Top.STL
    [NCCF_Top.STL]
2026-06-10 Rename Silicone Bottom.STL to Silicone_Bottom.STL
    [Silicone_Bottom.STL]
2026-06-10 Rename Silicone Top.STL to Silicone_Top.STL
    [Silicone_Top.STL]
2026-06-10 Update lab calibration GUI
